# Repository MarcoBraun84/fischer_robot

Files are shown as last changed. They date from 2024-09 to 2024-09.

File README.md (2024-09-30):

# Fischertechnik Robot Arm 9V Control with Raspberry Pi

This project involves controlling a Fischertechnik 9V robot arm using a Raspberry Pi. The project includes both software and hardware components to achieve full control of the robot arm through custom Python scripts and physical assembly of the robot arm using custom cases and parts.

## Requirements

To successfully complete the project, you will need the following components:

- **Fischertechnik Robot Arm**
- **Raspberry Pi 3 or 4**
- **SD Card**
- **Fischer Adapter PCB**(hardware/pcb/fischer_adapter.f3z)
- **Pi Adapter PCB**(hardware/pcb/pi_adapter.f3z)

## Project Structure

The repository is structured into two main sections:

- **Software**:
  - Contains all Python scripts necessary to control the robot arm, including motor control logic, GUI scripts, and sensor interfacing.
  - For detailed software setup and usage instructions, navigate to the `software/README.md` file.

- **Hardware**:
  - Contains CAD files, BOM, and assembly instructions for constructing the physical components
  - For detailed hardware setup and assembly instructions, navigate to the `hardware/README.md` file.

## Getting Started

### 1. **Software Setup**

To set up the software and control the robot arm via the Raspberry Pi:
1. Navigate to the `software/README.md` file for step-by-step instructions on installing the necessary Python libraries, running the control scripts, and using the GUI.
2. Ensure your Raspberry Pi is properly connected to the robot arm and follow the software guide to begin controlling the motors and sensors.

### 2. **Hardware Assembly**

To build the housing for the pi adapter and the mount for the fischer adapter:
1. Navigate to the `hardware/README.md` file for assembly instructions.
2. Review the Bill of Materials (BOM) and follow the step-by-step guide to assemble the components.

## License

This project is licensed under the MIT License. See the LICENSE file for more details.

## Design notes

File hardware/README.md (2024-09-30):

# fischer x pi - Hardware

This file includes the hardware assembly, setup and usage instructions.

# Setup after assembly

1. Connect the cables of the fischer technik sensors and motor so that they match the labeling on the `fischer_adaper` pcb (see `images/fischer_labels.png`)
2. Place the two components as shown in the picture below
3. Connect the 40 pin cable so that the red line remains on one side
4. Connect keyboard, mouse and display to the pi (alternatively vnc possible)
5. Connect the 9V power supply
6. Start software and have fun!

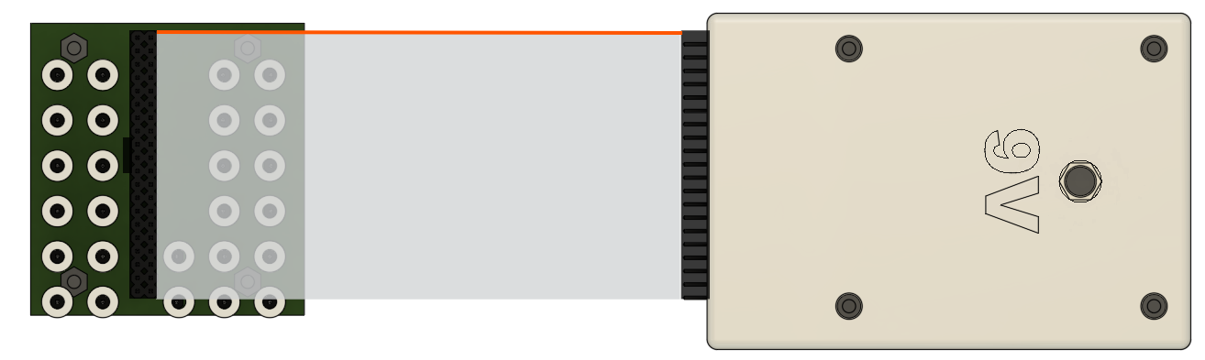
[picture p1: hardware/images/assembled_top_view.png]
assembled


# Assembly pi_adapter

1. Solder all components except for the 40 pin connector (female) to the pcb
2. Assemble the lower part of the device up to the 20 mm spacers (see `images/pi_adapter/*.png`)
3. Plug the 40 pin socket onto the pi
4. Insert the `pi_adapter` pcb through the holes of the socket and place it on the spacers
5. Solder the 40 pin header to it
6. Add the 14 mm spacers
7. Solder cables to the 9v socket and screw the socket to the cover
8. Solder the cables to the board or plug them into the pin headers from below
9. Put the cover on the spacers and screw it tight
10. Check that it looks like the picture below
11. Compare with another one

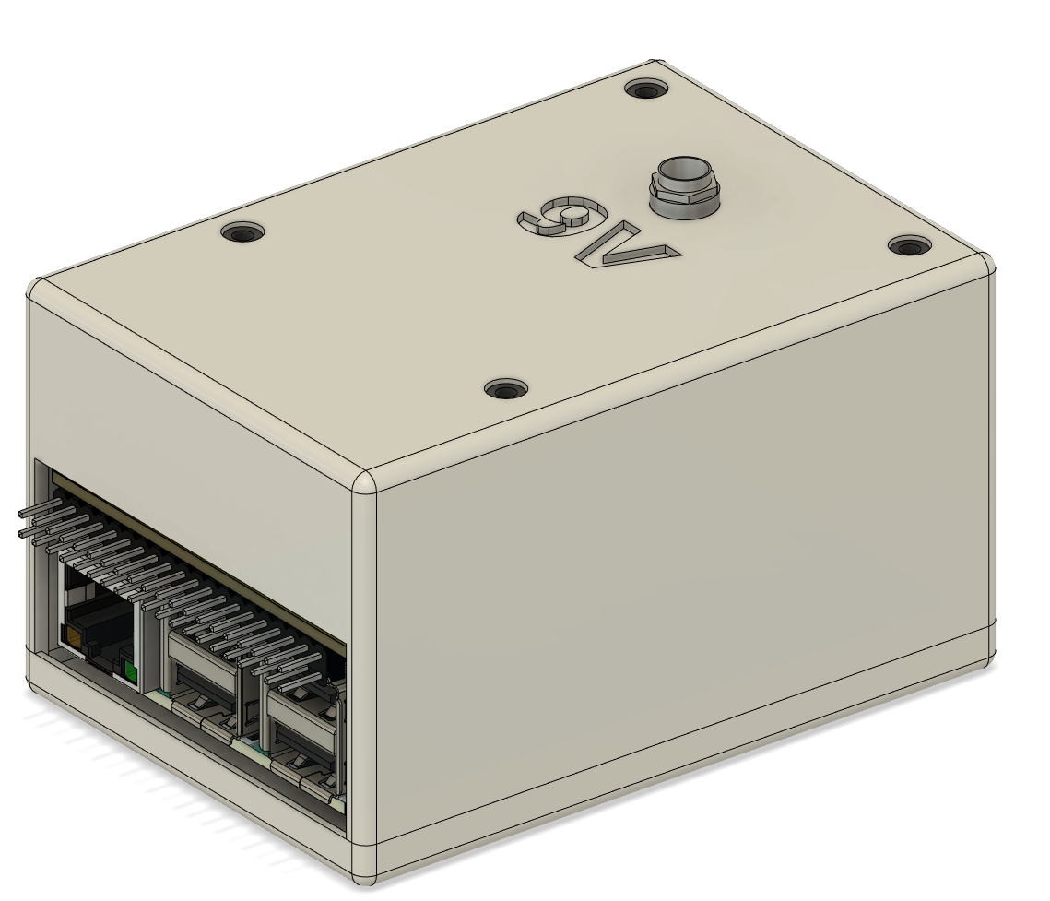
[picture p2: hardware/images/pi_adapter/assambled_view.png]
pi_adapter


# Assembly fischer_adapter

1. Screw 26 fischer sockets onto the individual pin headers
2. Solder the individual pin headers and the 40 pin header onto the `fischer_adapter` pcb
3. Screw the board onto the adapter backplate (see `images/fischer_adapter/*.png`)
4. Check that it looks like the picture below
15. Compare with another one

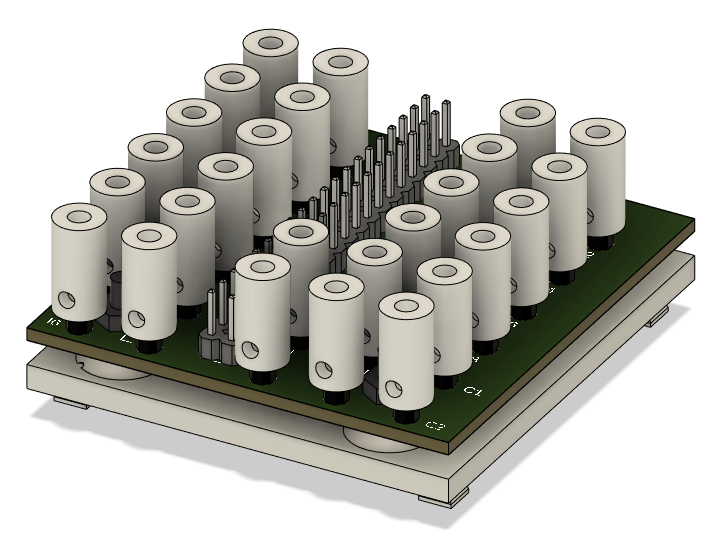
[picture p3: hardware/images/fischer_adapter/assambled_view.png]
fischer_adapter


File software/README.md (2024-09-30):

# fischer x pi - Software

This file includes the software setup, description and usage instructions.

# Setup

1. **Install Raspberry Pi OS on sd card**
    - (Legacy, 64-bit) Debian Bullseye with seqruity updates and desktop environment
    - Bookworm is not working with Rpi.GPIO lib!

2. **Create directory**

    Open terminal and run:
    ```zsh
    mkdir git
    cd git
    ```

3. **Clone repository from git**
    - ssh - Add ssh key in user settings
    - https - Add acces token with read access in user settings
    ```zsh
    git clone <url>
    ```
    The url can be found via the blue field

4. **Create virtual envrionment**
    ```zsh
    cd fischer_roboter
    python3 -m venv .venv
    ```

5. **Activate virtual environment**
    ```zsh
    source .venv/bin/activate
    ```

6. **Install requirements**
    ```zsh
    pip3 install -r requirements.txt
    ```

# fischer_main.py

The `fischer_main.py` script serves as the entry point for launching the graphical user interface (GUI) to control the Fischer robot arm using the `fischer_controller.py` script. It is a sample code to illustrate the use of the `fischer_lib.py`. It initializes the Tkinter window and starts the `MotorControllerApp`, which provides the interface for controlling the robot arm's motors and monitoring its limit switches and rotation counters.

## USAGE

To run the GUI and control the Fischer robot arm, follow these steps:

1. **Do the Setup**
    - Not necessary if already done
2. **Connect the Fischer robot arm**
    - Ensure the robot arm's motors and sensors are correctly connected to the adapter pcb
    - Check if the connection cable to the RaspberryPi is plugged the right way round.

3. **Run the application**

    Open new terminal in Desktop Environment:
    ```zsh
    cd git/fischer_robot
    source .venv/bin/activate
    python3 fischer_main.py
    ```

# fischer_lib.py

This library provides functionality to control a Fischer robot arm using a Raspberry Pi. The robot arm's motors and sensors are managed using the GPIO pins on the Pi, allowing control of arm movements and monitoring of the arm's position using limit switches and rotation counters.

## GPIO Pin Mapping

The following GPIO pins on the Raspberry Pi are used to control the motors and read input from limit switches and rotation sensors:

- **Motor control pins**
    | Motor | Positive | Negative |
    |:-----:|:--------:|:--------:|
    |   M1  |  GPIO 23 |  GPIO 27 |
    |   M2  |  GPIO 15 |  GPIO 22 |
    |   M3  |  GPIO 18 |  GPIO 10 |
    |   M4  |  GPIO 17 |  GPIO 9  |

- **Sensor pins**
  - Limit switches: T1, T2, T3, T5
  - Rotation sensors: E1, E2, T4, T6

## Classes and Methods

### 1. `Robot` Class

The `Robot` class is the main class that encapsulates the robot arm's behavior. It manages the motors and sensors of the robot and provides methods to control and home the robot arm.

#### Methods:

- **`__init__(self)`**:
  Initializes the robot, configuring its motors and limit switches. Starts threads for monitoring rotation and limits.

- **`auto_home(self)`**:
  Automatically homes the robot by rotating all motors in the clockwise direction until the limit switches are activated.

### 2. `Motor` Class

The `Motor` class controls individual motors of the robot arm. It provides methods to move the motors in both directions and monitors limit switches to ensure safe operation.

#### Methods:

- **`__init__(self, pin_plus, pin_minus, limit_switch, rotation_switch, range)`**:
  Initializes a motor with its GPIO pins for forward and backward movement, as well as associated limit and rotation switches.

- **`_check_limits(self)`**:
  Continuously checks the state of the motor's limit switch and rotation counter to stop the motor when necessary.

- **`clockwise(self)`**:
  Moves the motor in the clockwise direction.

- **`counterclockwise(self)`**:
  Moves the motor in the counterclockwise direction.

- **`stop(self)`**:
  Stops the motor by setting both motor control pins to LOW.

### 3. `Input` Class

The `Input` class handles sensor inputs from the limit switches and rotation sensors. It tracks the rotation of the motors and detects when a motor has reached its end position.

#### Methods:

- **`__init__(self, pin, motor)`**:
  Initializes an input sensor with its GPIO pin and the motor it is associated with.

- **`_count_flank(self, channel)`**:
  A callback function triggered by a GPIO interrupt to count motor rotations.

- **`start(self)`**:
  Starts the rotation detection by adding an event detect on the GPIO pin.

- **`counter(self)`**:
  Returns the current count of motor rotations.

- **`state(self)`**:
  Returns the state of the limit switch (whether it is triggered or not).

- **`stop(self)`**:
  Stops the rotation detection by removing the event detect.

- **`reset(self)`**:
  Resets the rotation counter to 0.

## Usage Example

Here is an example of how to use the `fischer_lib.py` library to control the Fischer robot arm:

```python
from fischer_lib import Robot

# Initialize the robot
robot = Robot()

# Move the robot arm to the home position
robot.auto_home()

# Control individual motors
robot.motor1.clockwise()  # Move motor 1 clockwise
time.sleep(1)             # Wait for 1 second
robot.motor1.stop()       # Stop motor 1
```

# fischer_controller.py

This project provides a graphical interface for controlling the motors of a Fischer robot arm using a Raspberry Pi. The graphical user interface (GUI) is built using Tkinter, and it allows for manual motor control as well as status monitoring of the limit switches and rotation sensors.

## GUI Layout

The GUI is divided into control panels for each motor, with the following components:

- **Motor Control Buttons**
    - **Clockwise**: Moves the motor clockwise.
    - **Counterclockwise**: Moves the motor counterclockwise.
    - **Stop**: Stops the motor.

- **Status Indicators**
    - **Limit Switch**: Displays the state of the motor's limit switch.
    - **Rotation Detection**: Displays the current rotation count of the motor.

- **Auto Home Button**: Moves all motors to their home position.

- **Reset Counter Button**: Resets the rotation detection counter for a motor.

## Classes and Methods

### 1. `MotorControllerApp` Class

This is the main class that creates the GUI for controlling the robot's motors. It initializes the GUI window and manages the control buttons for the motors as well as status updates for the limit switches and rotation sensors.

#### Methods:

- **`__init__(self, root)`**: Initializes the GUI and motor control components. It sets up buttons for each motor and starts a thread to continuously update the motor's status.

- **`create_header(self)`**: Creates the header for the GUI window, displaying the title "Fischer Roboterarm x Pi".

- **`create_auto_home_button(self)`**: Adds an "Auto Home" button to the GUI, which triggers the robot's `auto_home` function to automatically move the motors to their home positions.

- **`create_motor_frame(self, motor_label, motor, limit_switch, rotation_detection)`**: Creates a control panel for an individual motor. Each panel includes buttons for clockwise, counterclockwise, and stop actions. It also displays the current status of the limit switch and rotation detection sensor.

- **`button_pressed(self, motor, action)`**: Handles motor control button presses, triggering the appropriate action (clockwise, counterclockwise, or stop) for the motor.

- **`update_button_color(self, motor, button_type, color)`**: Resets the color of previously pressed buttons and updates the color of the currently pressed button to indicate the active action.

- **`reset_counter(self, counter)`**: Resets the rotation counter of the motor.

- **`update_status(self)`**: Continuously updates the status of the limit switches and rotation detection labels for all motors in real-time. This method runs in a separate thread.

## Usage
Start the GUI by running the `fischer_main.py` Python script.

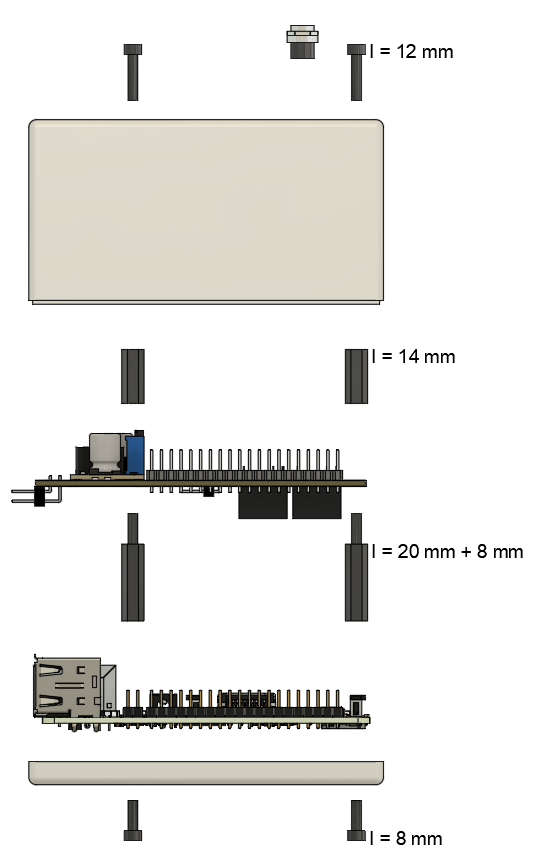
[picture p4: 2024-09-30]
hardware/images/pi_adapter/side_view.png

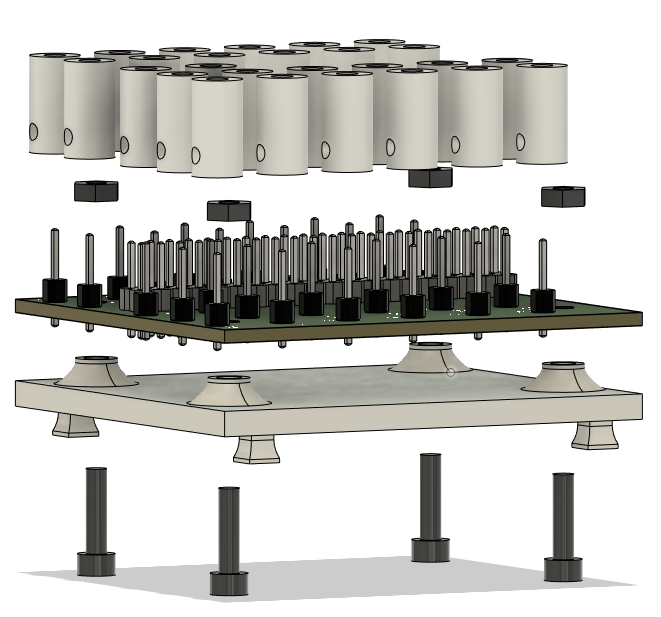
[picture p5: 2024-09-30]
hardware/images/fischer_adapter/exploded_view.png

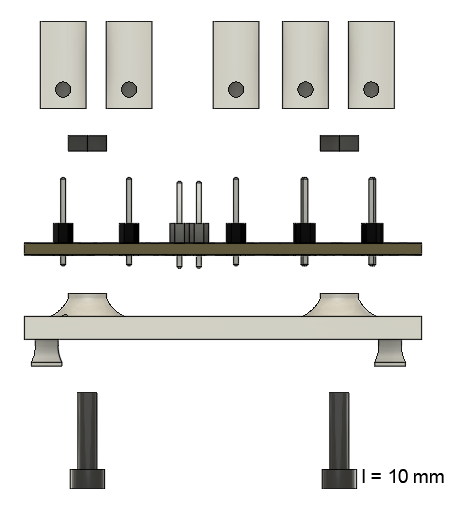
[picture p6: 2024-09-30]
hardware/images/fischer_adapter/side_view.png

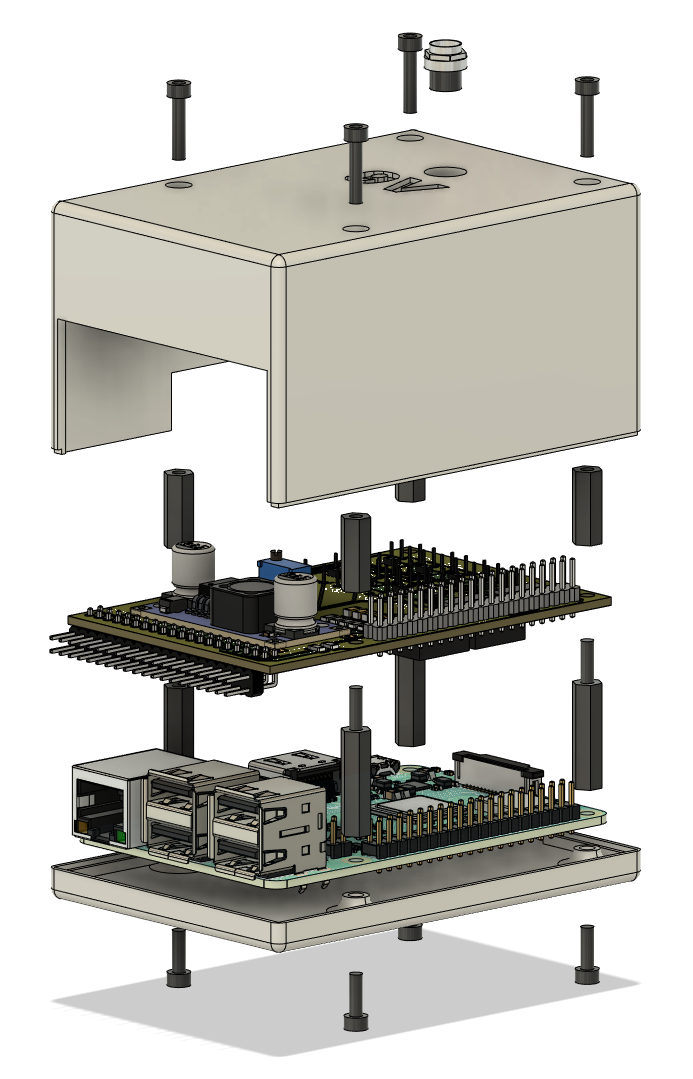
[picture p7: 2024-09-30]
hardware/images/pi_adapter/exploded_viev.png

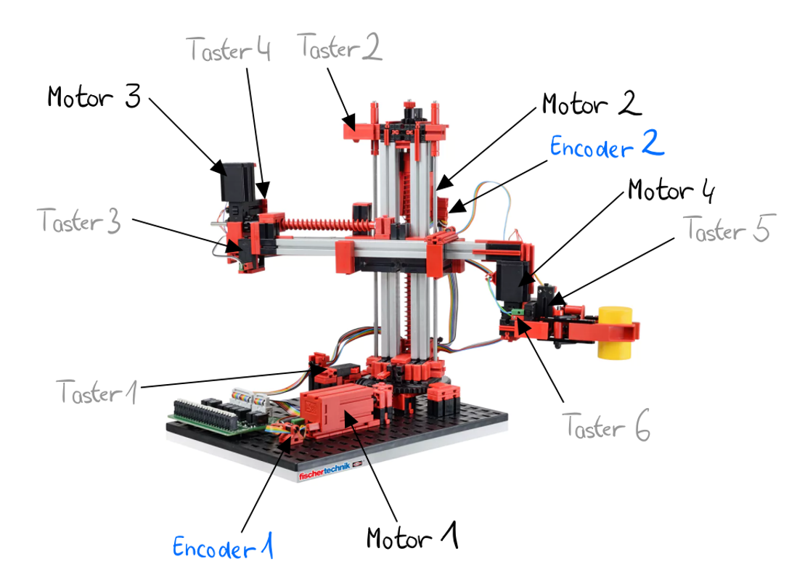
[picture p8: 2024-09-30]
hardware/images/fischer_labels.png

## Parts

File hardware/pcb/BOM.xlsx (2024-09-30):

Position | Name | Menge | Link | Zuordnung
1 | Pinheader 2x20 Buchse lang | 1 | Link (https://www.reichelt.de/raspberry-pi-stacking-header-40-polig-rm-2-54-rpi-header-40-p223626.html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) | pi_adpater
2 | Pinheader 1x2/90 Stecker | 1 | Link (https://www.reichelt.de/stiftleiste-rm-2-54mm-gewinkelt-1-reihig-2-polig-w-p-946-122-p330970.html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) | pi_adpater
3 | Pinheader 2x20/90 Stecker | 2 | Link (https://www.reichelt.de/stiftleiste-20-pin-rastermass-2-54-mm-2-reihig-gewinkelt-5-st-delock-66702-p371054.html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) | pi_adapter/fischer_adapter
4 | 40 Pin Kabel Female - Female | 1 | Link (https://www.reichelt.de/raspberry-pi-gpio-kabel-40-pin-15cm-grau-rpi-gpio40-150-p293571.html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) | pi_adapter/fischer_adapter
5 | SMD 1/4W 4,7K, 1206 | 2 | Link (https://www.reichelt.de/smd-widerstand-1206-4-7-kohm-250-mw-5--smd-1-4w-4-7k-p18330.html?trstct=pol_0&nbc=1) | pi_adpater
6 | SMD 1/4W 10K, 1206 | 6 | Link (https://www.reichelt.de/smd-widerstand-1206-10-kohm-250-mw-5--smd-1-4w-10k-p18244.html?trstct=pol_0&nbc=1) | pi_adpater
7 | X7R-G1206 22N, 1206 | 6 | Link (https://www.reichelt.de/vielschicht-kerko-1206-22-nf-10-x7r-50-v-125-c-ve-4k-x7r-g1206-22n-p31899.html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) | pi_adpater
8 | 1N 4148W7F DII; SOD123 | 8 | Link (https://www.reichelt.de/kleinsignal-schalt-diode-100-v-300-ma-sod-123-1n-4148w7f-dii-p219381.html) | pi_adpater
9 | ULN 2003 AD SMD, SO-16 | 2 | Link (https://www.reichelt.de/seven-darlington-arrays-so-16-uln-2003-ad-smd-p18887.html?trstct=pos_1&nbc=1) | pi_adpater
10 | G5V-15DC | 8 | Link (https://www.reichelt.de/signalrelais-thd-5-vdc-1-a-1-wechsler-g5v-1-5dc-p243067.html?trstct=pos_0&nbc=1) | pi_adpater
11 | LM2596 | 1 | Link (https://www.az-delivery.de/products/lm2596s-dc-dc-step-down-modul-1) | pi_adpater
12 | Pinheader 1x32 Stecker (für 26 mal 1x1 fischer_adapter) | 1 | Link (https://www.reichelt.de/praezisions-stiftleiste-32-polig-2-54mm-bkl-10120538-p235667.html?trstct=pol_0&nbc=1) | fischer_adapter
13 | FischerTechnik Buchse (26 Buchsen werden benötigt) | 3 | Link (https://www.ebay.de/itm/332905342520) | fischer_adapter
14 | Abstandshalter M2.5 / 14 mm Female-Female Polyamid | 4 | Link (https://www.digikey.de/de/products/detail/w%C3%BCrth-elektronik/970140155/9488709) | pi_adpater
15 | Abstandshalter M2.5 / 20 mm + 8 mm Male-Female Polyamid | 4 | Link (https://www.digikey.de/de/products/detail/w%C3%BCrth-elektronik/971200155/9488787) | pi_adpater
16 | Schraube M2.5 / 8 mm Innensechskant, Zylinderkopf | 4 |  | pi_adpater
17 | Schraube M2.5 / 12 mm Innensechskant, Zylinderkopf | 4 |  | pi_adpater
18 | Schraube M2.5 / 10 mm Innensechskant, Zylinderkopf | 4 |  | fischer_adapter
19 | Mutter M2.5 | 4 |  | fischer_adapter
20 | Einbaubuchse Stromversorgung |  | Link (https://www.reichelt.de/einbaubuchse-zentraleinbau-aussen-5-6-mm-innen-2-5-mm-hebl-25-p8525.html) | pi_adapter
21 | Netzteil 9V |  | Link (https://www.reichelt.de/steckernetzteil-18-w-9-v-2-a-hnp-18-090v2-p298327.html) | pi_adapter

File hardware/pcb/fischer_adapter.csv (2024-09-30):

Part | Value | Device | Package | Description | CATEGORY | DESCRIPTION | MANUFACTURER | MPN | OPERATING_TEMPERATURE | PART_STATUS | PITCH | POPULARITY | ROHS_COMPLIANCE | SERIES | SUB-CATEGORY | TYPE
01 | PINHD-1X1 | PINHD-1X1 | 1X01 | PIN HEADER | Headers | Header, Straight, 1 Position | Generic | Generic | Generic | Active | 0.100 (2.54mm)" |  | Generic | Generic | Headers, Male Pins | Board to Board or Cable, Unshrouded, Through Hole, Straight
02 | PINHD-1X1 | PINHD-1X1 | 1X01 | PIN HEADER | Headers | Header, Straight, 1 Position | Generic | Generic | Generic | Active | 0.100 (2.54mm)" |  | Generic | Generic | Headers, Male Pins | Board to Board or Cable, Unshrouded, Through Hole, Straight
03 | PINHD-1X1 | PINHD-1X1 | 1X01 | PIN HEADER | Headers | Header, Straight, 1 Position | Generic | Generic | Generic | Active | 0.100 (2.54mm)" |  | Generic | Generic | Headers, Male Pins | Board to Board or Cable, Unshrouded, Through Hole, Straight
04 | PINHD-1X1 | PINHD-1X1 | 1X01 | PIN HEADER | Headers | Header, Straight, 1 Position | Generic | Generic | Generic | Active | 0.100 (2.54mm)" |  | Generic | Generic | Headers, Male Pins | Board to Board or Cable, Unshrouded, Through Hole, Straight
05 | PINHD-1X1 | PINHD-1X1 | 1X01 | PIN HEADER | Headers | Header, Straight, 1 Position | Generic | Generic | Generic | Active | 0.100 (2.54mm)" |  | Generic | Generic | Headers, Male Pins | Board to Board or Cable, Unshrouded, Through Hole, Straight
06 | PINHD-1X1 | PINHD-1X1 | 1X01 | PIN HEADER | Headers | Header, Straight, 1 Position | Generic | Generic | Generic | Active | 0.100 (2.54mm)" |  | Generic | Generic | Headers, Male Pins | Board to Board or Cable, Unshrouded, Through Hole, Straight
07 | PINHD-1X1 | PINHD-1X1 | 1X01 | PIN HEADER | Headers | Header, Straight, 1 Position | Generic | Generic | Generic | Active | 0.100 (2.54mm)" |  | Generic | Generic | Headers, Male Pins | Board to Board or Cable, Unshrouded, Through Hole, Straight
08 | PINHD-1X1 | PINHD-1X1 | 1X01 | PIN HEADER | Headers | Header, Straight, 1 Position | Generic | Generic | Generic | Active | 0.100 (2.54mm)" |  | Generic | Generic | Headers, Male Pins | Board to Board or Cable, Unshrouded, Through Hole, Straight
C1 | PINHD-1X1 | PINHD-1X1 | 1X01 | PIN HEADER | Headers | Header, Straight, 1 Position | Generic | Generic | Generic | Active | 0.100 (2.54mm)" |  | Generic | Generic | Headers, Male Pins | Board to Board or Cable, Unshrouded, Through Hole, Straight
C2 | PINHD-1X1 | PINHD-1X1 | 1X01 | PIN HEADER | Headers | Header, Straight, 1 Position | Generic | Generic | Generic | Active | 0.100 (2.54mm)" |  | Generic | Generic | Headers, Male Pins | Board to Board or Cable, Unshrouded, Through Hole, Straight
I1 | PINHD-1X1 | PINHD-1X1 | 1X01 | PIN HEADER | Headers | Header, Straight, 1 Position | Generic | Generic | Generic | Active | 0.100 (2.54mm)" |  | Generic | Generic | Headers, Male Pins | Board to Board or Cable, Unshrouded, Through Hole, Straight
I2 | PINHD-1X1 | PINHD-1X1 | 1X01 | PIN HEADER | Headers | Header, Straight, 1 Position | Generic | Generic | Generic | Active | 0.100 (2.54mm)" |  | Generic | Generic | Headers, Male Pins | Board to Board or Cable, Unshrouded, Through Hole, Straight
I3 | PINHD-1X1 | PINHD-1X1 | 1X01 | PIN HEADER | Headers | Header, Straight, 1 Position | Generic | Generic | Generic | Active | 0.100 (2.54mm)" |  | Generic | Generic | Headers, Male Pins | Board to Board or Cable, Unshrouded, Through Hole, Straight
I4 | PINHD-1X1 | PINHD-1X1 | 1X01 | PIN HEADER | Headers | Header, Straight, 1 Position | Generic | Generic | Generic | Active | 0.100 (2.54mm)" |  | Generic | Generic | Headers, Male Pins | Board to Board or Cable, Unshrouded, Through Hole, Straight
I5 | PINHD-1X1 | PINHD-1X1 | 1X01 | PIN HEADER | Headers | Header, Straight, 1 Position | Generic | Generic | Generic | Active | 0.100 (2.54mm)" |  | Generic | Generic | Headers, Male Pins | Board to Board or Cable, Unshrouded, Through Hole, Straight
I6 | PINHD-1X1 | PINHD-1X1 | 1X01 | PIN HEADER | Headers | Header, Straight, 1 Position | Generic | Generic | Generic | Active | 0.100 (2.54mm)" |  | Generic | Generic | Headers, Male Pins | Board to Board or Cable, Unshrouded, Through Hole, Straight
JP2 | PINHD-1X1 | PINHD-1X1 | 1X01 | PIN HEADER | Headers | Header, Straight, 1 Position | Generic | Generic | Generic | Active | 0.100 (2.54mm)" |  | Generic | Generic | Headers, Male Pins | Board to Board or Cable, Unshrouded, Through Hole, Straight
JP4 | PINHD-1X1 | PINHD-1X1 | 1X01 | PIN HEADER | Headers | Header, Straight, 1 Position | Generic | Generic | Generic | Active | 0.100 (2.54mm)" |  | Generic | Generic | Headers, Male Pins | Board to Board or Cable, Unshrouded, Through Hole, Straight
JP6 | PINHD-1X1 | PINHD-1X1 | 1X01 | PIN HEADER | Headers | Header, Straight, 1 Position | Generic | Generic | Generic | Active | 0.100 (2.54mm)" |  | Generic | Generic | Headers, Male Pins | Board to Board or Cable, Unshrouded, Through Hole, Straight
JP8 | PINHD-1X1 | PINHD-1X1 | 1X01 | PIN HEADER | Headers | Header, Straight, 1 Position | Generic | Generic | Generic | Active | 0.100 (2.54mm)" |  | Generic | Generic | Headers, Male Pins | Board to Board or Cable, Unshrouded, Through Hole, Straight
JP10 | PINHD-1X1 | PINHD-1X1 | 1X01 | PIN HEADER | Headers | Header, Straight, 1 Position | Generic | Generic | Generic | Active | 0.100 (2.54mm)" |  | Generic | Generic | Headers, Male Pins | Board to Board or Cable, Unshrouded, Through Hole, Straight
JP12 | PINHD-1X1 | PINHD-1X1 | 1X01 | PIN HEADER | Headers | Header, Straight, 1 Position | Generic | Generic | Generic | Active | 0.100 (2.54mm)" |  | Generic | Generic | Headers, Male Pins | Board to Board or Cable, Unshrouded, Through Hole, Straight
JP21 | PINHD-1X1 | PINHD-1X1 | 1X01 | PIN HEADER | Headers | Header, Straight, 1 Position | Generic | Generic | Generic | Active | 0.100 (2.54mm)" |  | Generic | Generic | Headers, Male Pins | Board to Board or Cable, Unshrouded, Through Hole, Straight
JP23 | PINHD-1X1 | PINHD-1X1 | 1X01 | PIN HEADER | Headers | Header, Straight, 1 Position | Generic | Generic | Generic | Active | 0.100 (2.54mm)" |  | Generic | Generic | Headers, Male Pins | Board to Board or Cable, Unshrouded, Through Hole, Straight
JP27 |  | PINHD-2X20 | 2X20 | PIN HEADER |  |  |  |  |  |  |  | 12
V_C1 | PINHD-1X1 | PINHD-1X1 | 1X01 | PIN HEADER | Headers | Header, Straight, 1 Position | Generic | Generic | Generic | Active | 0.100 (2.54mm)" |  | Generic | Generic | Headers, Male Pins | Board to Board or Cable, Unshrouded, Through Hole, Straight
V_C2 | PINHD-1X1 | PINHD-1X1 | 1X01 | PIN HEADER | Headers | Header, Straight, 1 Position | Generic | Generic | Generic | Active | 0.100 (2.54mm)" |  | Generic | Generic | Headers, Male Pins | Board to Board or Cable, Unshrouded, Through Hole, Straight

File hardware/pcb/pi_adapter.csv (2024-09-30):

Part | Value | Device | Package | Description | CATEGORY | DESCRIPTION | FORWARD_CURRENT | MANUFACTURER | MPN | OPERATING_TEMP | PART_STATUS | POPULARITY | REVERSE_VOLTAGE | ROHS_COMPLIANT | SERIES | SUB-CATEGORY | THERMALLOSS | TYPE | VALUE
C1 | 22nF | C-EUC1206 | C1206 | CAPACITOR, European symbol
C2 | 22nF | C-EUC1206 | C1206 | CAPACITOR, European symbol
C3 | 22nF | C-EUC1206 | C1206 | CAPACITOR, European symbol
C4 | 22nF | C-EUC1206 | C1206 | CAPACITOR, European symbol
C5 | 22nF | C-EUC1206 | C1206 | CAPACITOR, European symbol
C6 | 22nF | C-EUC1206 | C1206 | CAPACITOR, European symbol
D1 | 1N4148W | DIODE_1N4148W-7-F_SOD123G | SOD3715X135 | Diode Rectifier - Popular parts | Diode | DIODE GEN PURP 100V 300MA SOD123 |  | Diodes Incorporated |  |  |  |  |  |  |  | Rectifier |  |  | 1N4148W
D2 | 1N4148W | DIODE_1N4148W-7-F_SOD123G | SOD3715X135 | Diode Rectifier - Popular parts | Diode | DIODE GEN PURP 100V 300MA SOD123 |  | Diodes Incorporated |  |  |  |  |  |  |  | Rectifier |  |  | 1N4148W
D3 | 1N4148W | DIODE_1N4148W-7-F_SOD123G | SOD3715X135 | Diode Rectifier - Popular parts | Diode | DIODE GEN PURP 100V 300MA SOD123 |  | Diodes Incorporated |  |  |  |  |  |  |  | Rectifier |  |  | 1N4148W
D4 | 1N4148W | DIODE_1N4148W-7-F_SOD123G | SOD3715X135 | Diode Rectifier - Popular parts | Diode | DIODE GEN PURP 100V 300MA SOD123 |  | Diodes Incorporated |  |  |  |  |  |  |  | Rectifier |  |  | 1N4148W
D5 | 1N4148W | DIODE_1N4148W-7-F_SOD123G | SOD3715X135 | Diode Rectifier - Popular parts | Diode | DIODE GEN PURP 100V 300MA SOD123 |  | Diodes Incorporated |  |  |  |  |  |  |  | Rectifier |  |  | 1N4148W
D6 | 1N4148W | DIODE_1N4148W-7-F_SOD123G | SOD3715X135 | Diode Rectifier - Popular parts | Diode | DIODE GEN PURP 100V 300MA SOD123 |  | Diodes Incorporated |  |  |  |  |  |  |  | Rectifier |  |  | 1N4148W
D7 | 1N4148W | DIODE_1N4148W-7-F_SOD123G | SOD3715X135 | Diode Rectifier - Popular parts | Diode | DIODE GEN PURP 100V 300MA SOD123 |  | Diodes Incorporated |  |  |  |  |  |  |  | Rectifier |  |  | 1N4148W
D8 | 1N4148W | DIODE_1N4148W-7-F_SOD123G | SOD3715X135 | Diode Rectifier - Popular parts | Diode | DIODE GEN PURP 100V 300MA SOD123 |  | Diodes Incorporated |  |  |  |  |  |  |  | Rectifier |  |  | 1N4148W
IC1 | ULN2003AD | ULN2003AD | SO16 | DRIVER ARRAY |  |  |  |  |  |  |  | 2
IC2 | ULN2003AD | ULN2003AD | SO16 | DRIVER ARRAY |  |  |  |  |  |  |  | 2
JP1 |  | PINHD-2X20 | 2X20 | PIN HEADER |  |  |  |  |  |  |  | 12
JP5 |  | PINHD-1X2/90 | 1X02/90 | PIN HEADER |  |  |  |  |  |  |  | 24
JP6 |  | PINHD-2X20/90 | 2X20/90 | PIN HEADER |  |  |  |  |  |  |  | 0
R1 | 4.7k | R-EU_R1206 | R1206 | RESISTOR, European symbol
R2 | 4.7kO | R-EU_R1206 | R1206 | RESISTOR, European symbol
R3 | 10k | R-EU_R1206 | R1206 | RESISTOR, European symbol
R4 | 10k | R-EU_R1206 | R1206 | RESISTOR, European symbol
R5 | 10k | R-EU_R1206 | R1206 | RESISTOR, European symbol
R6 | 10k | R-EU_R1206 | R1206 | RESISTOR, European symbol
R7 | 10k | R-EU_R1206 | R1206 | RESISTOR, European symbol
R8 | 10k | R-EU_R1206 | R1206 | RESISTOR, European symbol
U$1 | G5V-1-DC5 | G5V-1-DC5 | G5V-1-DC5
U$2 | G5V-1-DC5 | G5V-1-DC5 | G5V-1-DC5
U$3 | LM2596_DC-DC | LM2596_DC-DC | LM2596_DC-DC
U$4 | G5V-1-DC5 | G5V-1-DC5 | G5V-1-DC5
U$5 | G5V-1-DC5 | G5V-1-DC5 | G5V-1-DC5
U$6 | G5V-1-DC5 | G5V-1-DC5 | G5V-1-DC5
U$7 | G5V-1-DC5 | G5V-1-DC5 | G5V-1-DC5
U$8 | G5V-1-DC5 | G5V-1-DC5 | G5V-1-DC5
U$9 | G5V-1-DC5 | G5V-1-DC5 | G5V-1-DC5

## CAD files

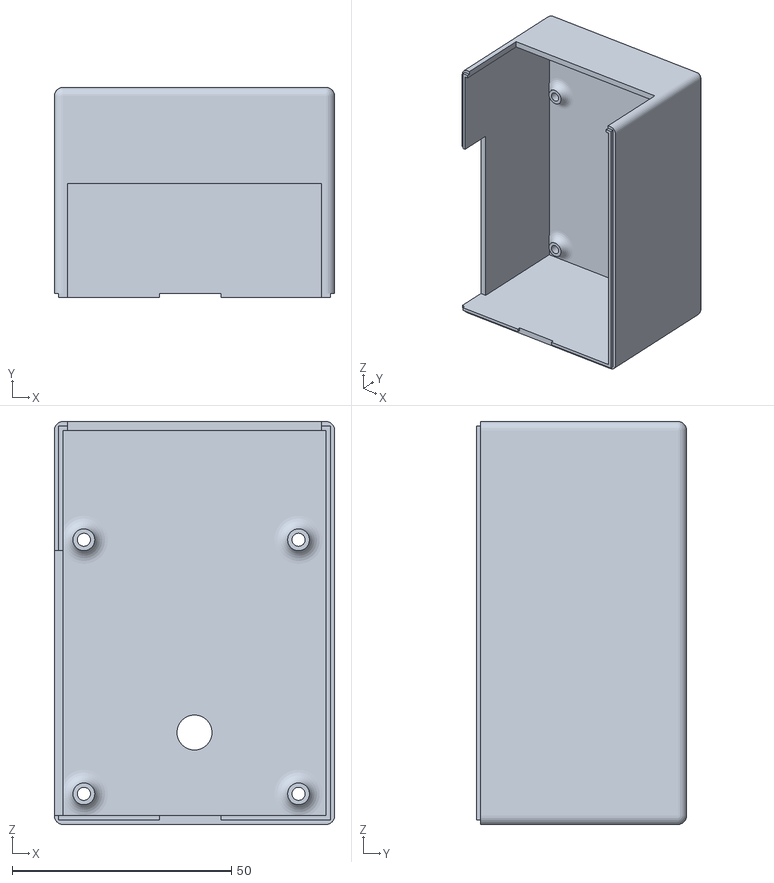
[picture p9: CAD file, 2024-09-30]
hardware/case/top.stl
64.0 x 48.0 x 92.0

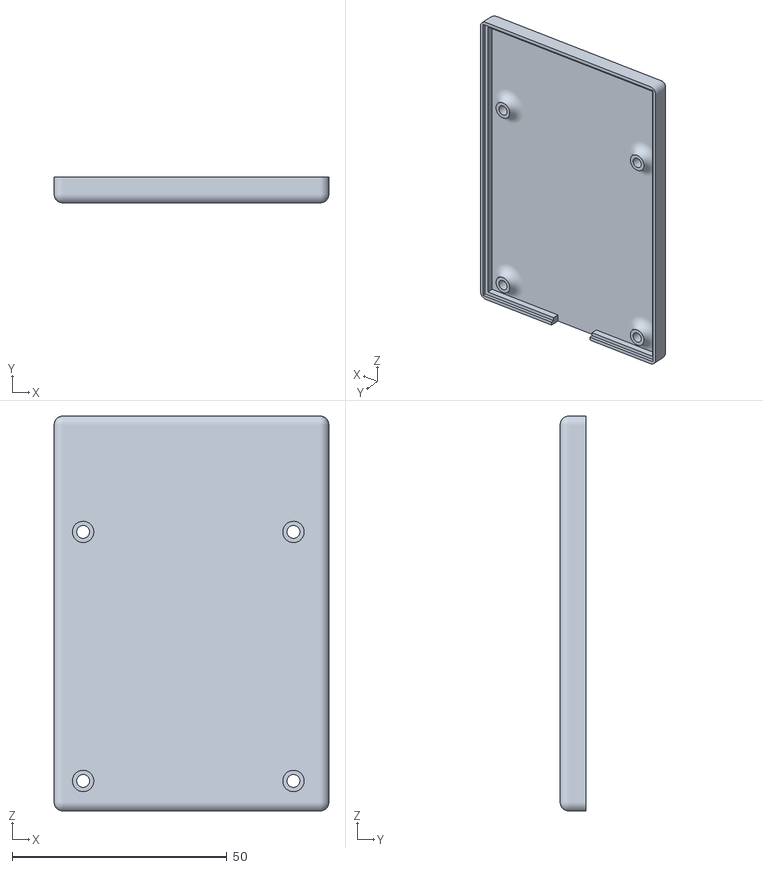
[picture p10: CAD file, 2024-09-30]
hardware/case/bottom.stl
64.0 x 6.00 x 92.0

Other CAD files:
hardware/pcb/fischer_adapter.f3z

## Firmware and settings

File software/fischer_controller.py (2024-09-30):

import tkinter as tk
from threading import Thread
import time
import fischer_lib as fl

class MotorControllerApp:
    """
    Main class for creating the GUI motor controller.

    This class creates a Tkinter-based graphical interface for controlling the Fischer robot arm motors.
    It provides buttons for each motor to move clockwise, counterclockwise, or stop, along with
    real-time status updates for limit switches and rotation detection.
    """
    def __init__(self, root):
        """
        Initializes the GUI window and sets up motor controls and status updates.

        Args:
        - root (tk.Tk): The root window for the Tkinter GUI.
        """
        self.root = root
        self.root.title("Motor Controller")

        self.robi = fl.Robot()

        self.last_pressed_button = {
            self.robi.motor1: {'clockwise': None, 'counterclockwise': None, 'stop': None},
            self.robi.motor2: {'clockwise': None, 'counterclockwise': None, 'stop': None},
            self.robi.motor3: {'clockwise': None, 'counterclockwise': None, 'stop': None},
            self.robi.motor4: {'clockwise': None, 'counterclockwise': None, 'stop': None},
        }

        self.motor_count = 1

        self.create_header()
        self.create_auto_home_button()
        self.motor1_frame, self.limit_switch_label1, self.rotation_detection_label1 = self.create_motor_frame("Motor 1", self.robi.motor1, self.robi.m1_limit_switch, self.robi.m1_rotation_dect)
        self.motor2_frame, self.limit_switch_label2, self.rotation_detection_label2 = self.create_motor_frame("Motor 2", self.robi.motor2, self.robi.m2_limit_switch, self.robi.m2_rotation_dect)
        self.motor3_frame, self.limit_switch_label3, self.rotation_detection_label3 = self.create_motor_frame("Motor 3", self.robi.motor3, self.robi.m3_limit_switch, self.robi.m3_rotation_dect)
        self.motor4_frame, self.limit_switch_label4, self.rotation_detection_label4 = self.create_motor_frame("Motor 4", self.robi.motor4, self.robi.m4_limit_switch, self.robi.m4_rotation_dect)

        self.update_status_thread = Thread(target=self.update_status, daemon=True)
        self.update_status_thread.start()

    def create_header(self):
        """
        Creates the header for the GUI window, displaying the title.
        """
        header_label = tk.Label(self.root, text="Fischer Roboterarm x Pi", font=("Helvetica", 18, "bold"))
        header_label.grid(row=0, column=2, pady=10)

    def create_auto_home_button(self):
        """
        Creates a button in the GUI for the "Auto Home" feature, which moves all motors to their home positions.
        """
        auto_home_button = tk.Button(self.root, text="Auto Home", command=self.robi.auto_home, bg='gray')
        auto_home_button.grid(row=0, column=4, padx=10, pady=10)

    def create_motor_frame(self, motor_label, motor, limit_switch, rotation_detection):
        """
        Creates a control panel for a motor, including buttons for clockwise, counterclockwise, stop, and status indicators.

        Args:
        - motor_label (str): The label for the motor (e.g., "Motor 1").
        - motor (Motor): The motor object to control.
        - limit_switch (Input): The limit switch associated with the motor.
        - rotation_detection (Input): The rotation detection sensor for the motor.

        Returns:
        - frame (tk.Frame): The frame containing the motor control panel.
        - limit_switch_label (tk.Label): Label displaying the current state of the limit switch.
        - rotation_detection_label (tk.Label): Label displaying the current count of rotations.
        """
        frame = tk.Frame(self.root, padx=10, pady=10)
        frame.grid(row=1, column=self.motor_count)

        self.motor_count += 1

        label = tk.Label(frame, text=motor_label, font='bold')
        label.pack()

        clockwise_button = tk.Button(frame, text="Clockwise", command=lambda: self.button_pressed(motor, 'clockwise'), state=tk.NORMAL, bg='gray')
        clockwise_button.pack(pady=5)

        counterclockwise_button = tk.Button(frame, text="Counterclockwise", command=lambda: self.button_pressed(motor, 'counterclockwise'), state=tk.NORMAL, bg='gray')
        counterclockwise_button.pack(pady=5)

        stop_button = tk.Button(frame, text="Stop", command=lambda: self.button_pressed(motor, 'stop'), state=tk.NORMAL, bg='red')
        stop_button.pack(pady=5)

        self.last_pressed_button[motor]['clockwise'] = clockwise_button
        self.last_pressed_button[motor]['counterclockwise'] = counterclockwise_button
        self.last_pressed_button[motor]['stop'] = stop_button

        limit_switch_header = tk.Label(frame, text="\nLimit Switch", font='bold')
        limit_switch_header.pack()

        limit_switch_label = tk.Label(frame, text=f"{limit_switch.state()}")
        limit_switch_label.pack()

        rotation_detection_header = tk.Label(frame, text="\nRotation Detection", font='bold')
        rotation_detection_header.pack()

        rotation_detection_label = tk.Label(frame, text=f"{rotation_detection.counter()}")
        rotation_detection_label.pack()

        reset_button = tk.Button(frame, text="Reset Counter", command=lambda: self.reset_counter(rotation_detection), bg='gray')
        reset_button.pack(pady=5)

        return frame, limit_switch_label, rotation_detection_label

    def button_pressed(self, motor, action):
        """
        Handles motor control button presses and triggers motor movement or stops the motor.

        Args:
        - motor (Motor): The motor to control.
        - action (str): The action to perform ('clockwise', 'counterclockwise', or 'stop').
        """
        if action == 'clockwise':
            motor.clockwise()
            self.update_button_color(motor, 'clockwise', 'green')
        elif action == 'counterclockwise':
            motor.counterclockwise()
            self.update_button_color(motor, 'counterclockwise', 'green')
        elif action == 'stop':
            motor.stop()
            self.update_button_color(motor, 'stop', 'red')

    def update_button_color(self, motor, button_type, color):
        """
        Resets the color of previously pressed buttons and updates the color of the currently pressed button.

        Args:
        - motor (Motor): The motor being controlled.
        - button_type (str): The type of button pressed ('clockwise', 'counterclockwise', or 'stop').
        - color (str): The color to apply to the pressed button.
        """
        for btn_type, button in self.last_pressed_button[motor].items():
            if btn_type != button_type:
                button.config(bg='gray')

        current_pressed_button = self.last_pressed_button[motor][button_type]
        current_pressed_button.config(bg=color)

    def reset_counter(self, counter):
        """
        Resets the rotation counter of a motor.
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

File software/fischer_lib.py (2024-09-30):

import RPi.GPIO as GPIO
import threading
import time

# GPIO-Initialization
GPIO.setmode(GPIO.BCM)

GPIO.setwarnings(False)

# GPIO-Pin-Assignment
D_M1_positive = 23
D_M1_negative = 27
D_M2_positive = 15
D_M2_negative = 22
D_M3_positive = 18
D_M3_negative = 10
D_M4_positive = 17
D_M4_negative = 9
D_T1 = 11
D_T2 = 1
D_T3 = 0
D_T4 = 5
D_T5 = 12
D_T6 = 6
D_E1 = 13
D_E2 = 19

# Thresholds
M1_Limit = 1700
M2_Limit = 1500
M3_Limit = 200
M4_Limit = 28

class Robot:
    """
    Main class for controlling the robot arm.

    The Robot class initializes and manages four motors and their associated limit switches
    and rotation sensors. It provides methods to control motor movements and homing functionality.
    """
    def __init__(self):
        """
        Initializes the Robot object by setting up motors and sensors for all four axes.
        """
        self.m1_limit_switch = Input(D_T1, None)
        self.m2_limit_switch = Input(D_T2, None)
        self.m3_limit_switch = Input(D_T3, None)
        self.m4_limit_switch = Input(D_T5, None)
        self.m1_rotation_dect = Input(D_E1, None)
        self.m2_rotation_dect = Input(D_E2, None)
        self.m3_rotation_dect = Input(D_T4, None)
        self.m4_rotation_dect = Input(D_T6, None)

        self.motor1 = Motor(D_M1_positive, D_M1_negative, self.m1_limit_switch, self.m1_rotation_dect, M1_Limit)
        self.motor2 = Motor(D_M2_positive, D_M2_negative, self.m2_limit_switch, self.m2_rotation_dect, M2_Limit)
        self.motor3 = Motor(D_M3_positive, D_M3_negative, self.m3_limit_switch, self.m3_rotation_dect, M3_Limit)
        self.motor4 = Motor(D_M4_positive, D_M4_negative, self.m4_limit_switch, self.m4_rotation_dect, M4_Limit)

        self.m1_limit_switch.motor = self.motor1
        self.m2_limit_switch.motor = self.motor2
        self.m3_limit_switch.motor = self.motor3
        self.m4_limit_switch.motor = self.motor4
        self.m1_rotation_dect.motor = self.motor1
        self.m2_rotation_dect.motor = self.motor2
        self.m3_rotation_dect.motor = self.motor3
        self.m4_rotation_dect.motor = self.motor4

        self.m1_rotation_dect.start()
        self.m2_rotation_dect.start()
        self.m3_rotation_dect.start()
        self.m4_rotation_dect.start()

    def auto_home(self):
        """
        Automatically moves all four motors clockwise to home the robot arm by hitting the limit switches.
        """
        self.motor1.clockwise()
        self.motor2.clockwise()
        self.motor3.clockwise()
        self.motor4.clockwise()

class Motor:
    """
    Class for controlling an individual motor of the robot arm.

    It controls motor movement (clockwise, counterclockwise), and monitors motor limits and rotations.
    """
    def __init__(self, pin_positive, pin_negative, limit_switch, rotation_switch, range):
        """
        Initializes the motor with the GPIO pins for forward and backward movement, limit and rotation switches,
        and the range for counterclockwise movement.

        Args:
        - pin_positive (int): GPIO pin for clockwise movement.
        - pin_negative (int): GPIO pin for counterclockwise movement.
        - limit_switch (Input): The limit switch for stopping motor.
        - rotation_switch (Input): The sensor tracking motor rotation.
        - range (int): The maximum allowable rotation for counterclockwise movement.
        """
        self.pin_positive = pin_positive
        self.pin_negative = pin_negative
        self.limit_switch = limit_switch
        self.rotation_switch = rotation_switch
        self.range = range

        self.is_running = False
        self.state = "stop"

        GPIO.setup(pin_positive, GPIO.OUT)
        GPIO.setup(pin_negative, GPIO.OUT)
        GPIO.output(self.pin_positive, GPIO.LOW)
        GPIO.output(self.pin_negative, GPIO.LOW)

        self.lock = threading.Lock()

        self.limit_thread = threading.Thread(target=self._check_limits)
        self.limit_thread.daemon = True
        self.limit_thread.start()

    def _check_limits(self):
        """
        Continuously monitors motor's limit switch and rotation counter to stop movement when necessary.
        This method runs in a background thread.
        """
        while True:
            with self.lock:
                if self.is_running:
                    if not self.limit_switch.state() and self.state == "clockwise":
                        self.rotation_switch.reset()
                        self.stop()
                    elif (self.rotation_switch.counter() > self.range) and self.state == "counterclockwise":
                        self.stop()
                time.sleep(0.1)

    def clockwise(self):
        """
        Moves the motor in the clockwise direction if the limit switch is not triggered.
        """
        if self.limit_switch.state():
            GPIO.output(self.pin_positive, GPIO.HIGH)
            GPIO.output(self.pin_negative, GPIO.LOW)
            self.state = "clockwise"
            self.is_running = True

    def counterclockwise(self):
        """
        Moves the motor in the counterclockwise direction if the rotation counter is below the allowed range.
        """
        if self.rotation_switch.counter() < self.range:
            GPIO.output(self.pin_positive, GPIO.LOW)
            GPIO.output(self.pin_negative, GPIO.HIGH)
            self.state = "counterclockwise"
            self.is_running = True

    def stop(self):
        """
        Stops the motor by setting both control GPIO pins to LOW.
        """
        GPIO.output(self.pin_positive, GPIO.LOW)
        GPIO.output(self.pin_negative, GPIO.LOW)
        self.state = "stop"
        self.is_running = False
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
